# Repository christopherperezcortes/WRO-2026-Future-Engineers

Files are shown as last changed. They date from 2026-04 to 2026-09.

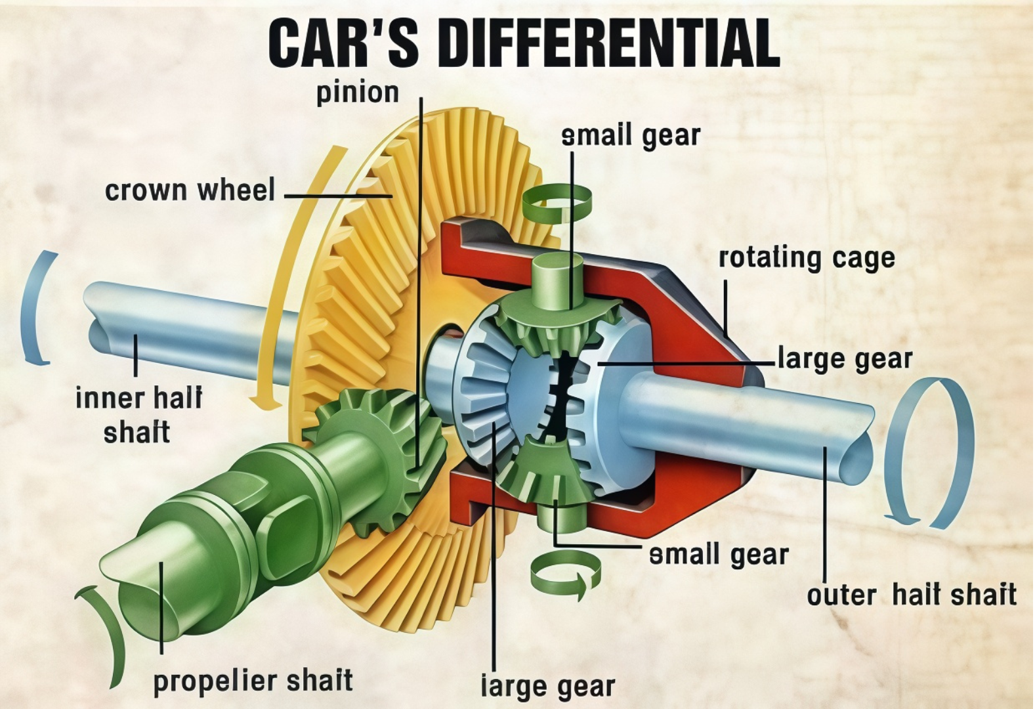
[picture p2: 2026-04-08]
OTHERS/CAR´S DIFFERENTIAL.png

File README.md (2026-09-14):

# Superiores — WRO 2026 Future Engineers

Team Superiores banner

This repository contains the engineering documentation, source code, mechanical designs, electrical system and test evidence for Team Superiores' autonomous vehicle for WRO 2026 Future Engineers.

## Team and competition

- **Team:** Superiores / Los Grises Superiores
- **Category:** WRO 2026 Future Engineers
- **Vehicle type:** Four-wheel autonomous vehicle with rear traction and front Ackermann-style steering
- **Students:** Christopher Pérez Cortés and Bárbara Daiana García Balboa
- **Coach:** Eduardo Alvarado González
- **Country:** Mexico
- **Competition event:** [PENDING: official event name and date]

WRO 2026 requires the Open Challenge vehicle to complete three laps. In the Obstacle Challenge it must complete three laps, obey red and green traffic signs, return to the starting section and perform parallel parking.

## Project status

The final physical robot uses a distributed three-controller architecture:

- A DFRobot FireBeetle ESP32 is the main controller.
- An Arduino Nano reads five HC-SR04 ultrasonic sensors and controls the lighting.
- An OpenMV camera performs color and shape detection.
- A BNO085 supplies fused heading data.
- A TB6612FNG drives the rear traction motor.
- A micro-servo actuates the steering rack.

The current software evidence contains two obstacle variants:

1. A three-lap build that stops without parking.
2. A four-lap experimental build containing parking logic.

Neither should be declared as the final WRO competition build until the parking logic starts immediately after the third lap and is validated on the official parking geometry.

The Open Challenge build must also have Wi-Fi disabled and use the WRO-required start-button procedure before it is tagged as a competition release.

## Design objectives

Our design objectives are:

1. Remain inside the WRO limit of 300 × 200 × 300 mm.
2. Remain below 1.5 kg.
3. Use a mechanically linked driving axle instead of differential steering.
4. Maintain controllable steering in both 600 mm and 1000 mm corridors.
5. Detect red and green pillars early enough to pass on the required side.
6. Count laps in clockwise and counter-clockwise rounds.
7. Stop safely when critical sensing or communication is lost.
8. Complete repeatable parallel parking after exactly three obstacle laps.
9. Make the vehicle reproducible from public source code, CAD, wiring and test records.

Current measured dimensions: **[PENDING: length × width × height]**

Competition-ready weight: **[PENDING: measured weight with batteries]**

## System architecture

```mermaid
flowchart LR
    BAT["2 × 18650 battery pack<br/>7.4 V nominal"]
    SW["Power switch"]
    REG5["5 V regulation"]
    REG33["3.3 V regulation"]
    SERREG["Servo 5 V rail"]
    LEDREG["LED 5 V rail"]
    ESP["FireBeetle ESP32<br/>main controller"]
    NANO["Arduino Nano<br/>sensor hub"]
    CAM["OpenMV<br/>vision processor"]
    IMU["BNO085<br/>fused heading"]
    US["5 × HC-SR04"]
    ENC["Motor encoder"]
    TB["TB6612FNG"]
    MOTOR["Rear traction motor"]
    SERVO["Steering servo"]
    LED["NeoPixel lighting"]

    BAT --> SW
    BAT --> REG5
    BAT --> REG33
    BAT --> SERREG
    BAT --> LEDREG
    SW --> TB
    REG5 --> ESP
    REG5 --> NANO
    REG5 --> US
    REG33 --> CAM
    REG33 --> IMU
    SERREG --> SERVO
    LEDREG --> LED

    US --> NANO
    NANO <-->|"I2C 0x08"| ESP
    IMU -->|"I2C 0x4B/0x4A"| ESP
    CAM -->|"UART 19200, CSV"| ESP
    ESP -->|"P,0 / P,1 and telemetry"| CAM
    ENC --> ESP
    ESP --> TB
    TB --> MOTOR
    ESP --> SERVO
    ESP -->|"brightness command"| NANO
    NANO --> LED
```

The electrical diagram reflects the current PCB evidence. Exact regulator loading, battery capacity, protection devices and installed LED topology remain to be measured or confirmed.

## Mechanical design

### Chassis

The 2026 chassis replaced an earlier LEGO-based prototype with printed structural parts. The reason reported in the Engineering Journal was that the LEGO structure occupied too much space and made electronics and sensor placement difficult.

The printed structure includes:

- Lower and upper chassis bodies.
- Front steering structure.
- Central and lateral ultrasonic mounts.
- Rear supports.
- Camera and electronics mounting areas.
- Mounting points for LEGO Technic drivetrain and steering elements.

Development evidence records two important mechanical iterations:

- Parts were sanded when printed clearances did not fit the motor and servo.
- The final chassis needed additional clearance around the drivetrain after a reprint created excessive friction.

The repository currently contains renders only. Native CAD, STL, STEP, drawings, print settings and revision identifiers are required in [`models/`](models/).

### Ackermann-style steering

The front axle uses a micro-servo and a rack-and-pinion linkage. The linkage causes the front wheels to steer together without using differential drive.

Current software settings are:

- Servo center: 90°.
- Maximum software correction: ±40°.
- PWM frequency: 50 Hz.
- Pulse range: 500–2500 µs.
- Parking correction magnitude: 38° in the experimental build.

The exact installed servo is **[PENDING: SG90 or Steren MOT-110, confirmed by a label photograph]**.

To make the Ackermann claim reproducible, the project still needs:

- Wheelbase.
- Front and rear track widths.
- Inner and outer wheel angles.
- Rack travel.
- Minimum turning radius.
- Drawing of steering pivots and tie-rod geometry.

### Traction

The robot uses one rear traction motor connected mechanically to the rear wheels through gearing/differential components. The motor is controlled by channel A of a TB6612FNG.

Current source settings:

- Open Challenge normal command: 100%.
- Open Challenge corner/near-wall minimum: 70%.
- Obstacle Challenge normal command: 70%.
- Obstacle visual-alert command: 40%.
- Obstacle reverse recovery: 45%.
- Parking approach/manoeuvre: 20%/18%.

These percentages are controller commands, not measured linear speeds. Motor model, no-load RPM, stall torque, gearbox ratio and measured vehicle speed are still required.

## Electronics

### Power architecture

The schematic shows a nominal 7.4 V two-cell 18650 supply, a motor-power switch, two Mini-560 regulator modules, two 7805 regulators, a voltmeter and separate named rails for logic, OpenMV/BNO085, servo and LEDs.

The current schematic does not show a fuse or reverse-polarity protection. Earlier development documentation records a reversed-battery incident that damaged a PCB. Protection must be added only after it is actually designed, installed and tested; it must not be claimed in documentation beforehand.

Measured power budget: **[PENDING: publish rail voltage, average current, peak current and regulator temperature]**

### Controllers

| Controller | Real responsibility |
|---|---|
| FireBeetle ESP32 | Main mission logic, steering, motor, BNO085, encoder, lap count, sensor fusion and communications |
| Arduino Nano | Sequential acquisition of five HC-SR04 sensors, I2C slave packet and NeoPixel output |
| OpenMV | QVGA color/shape processing for pillars, collision area, black-wall ROI and magenta parking boundaries |

### Sensors

#### Five HC-SR04 sensors

| Sensor | Position | Nano pins | Main use |
|---|---|---|---|
| S1 | Left, 90° | TRIG D2 / ECHO D3 | Outer-left distance and parking boundary |
| S2 | Left, 25° | TRIG D4 / ECHO D5 | Left corridor alignment |
| S3 | Front | TRIG D6 / ECHO D7 | Corner proximity, emergency reverse and parking stop |
| S4 | Right, 25° | TRIG D8 / ECHO D9 | Right corridor alignment |
| S5 | Right, 90° | TRIG D10 / ECHO D11 | Outer-right distance and parking boundary |

The Nano scans in the order S3, S1, S5, S2, S4. Each echo has a 12 ms timeout and a 2,000 mm maximum accepted distance. Invalid values are transmitted as `0xFFFF`.

#### BNO085

The BNO085 shares the I2C bus with the Nano and is tried at addresses `0x4B` and `0x4A`. The ESP32 requests `SH2_GAME_ROTATION_VECTOR` reports every 10 ms and derives yaw from the quaternion.

The BNO085 is used for:

- Locking the clockwise/counter-clockwise turn sign.
- Accumulating heading changes.
- Confirming each 90° corner.
- Counting three laps.
- Guiding reverse recovery.
- Controlling parking arc/contra-arc heading in the experimental build.

#### OpenMV

The camera captures QVGA RGB565 images at 320 × 240. It initially enables automatic gain, white balance and exposure, waits 800 ms, then freezes the selected values. The exact exposure remains automatic at boot and must be recorded during final calibration.

UART settings:

- OpenMV UART bus 3.
- ESP32 UART2.
- 19200 baud, 8N1.
- OpenMV TX → ESP32 RX/GPIO25.
- OpenMV RX ← ESP32 TX/GPIO26.
- Shared ground.

## Software architecture

Complete software details are in [`src/README.md`](src/README.md).

### Main data flow

```mermaid
flowchart LR
    U["Five ultrasonic readings"] --> F["Validity checks and last-echo retention"]
    C["OpenMV blobs and parking fields"] --> P["Frame validation and target selection"]
    B["BNO085 quaternion"] --> Y["Yaw and corner accumulation"]
    E["Encoder pulses"] --> S["Start/movement and parking progress"]
    F --> D["Mission decision"]
    P --> D
    Y --> D
    S --> D
    D --> ST["Steering command"]
    D --> MT["Motor command"]
    D --> FB["Failsafe / recovery / stop"]
```

### Open Challenge

The Open program uses the left/right ultrasonic error:

```text
error = (S1 + S2) - (S4 + S5)
```

It applies PID control with:

- `KP = 0.04`
- `KI = 0.001`
- `KD = 0.003`
- Integral contribution limited to ±8°.
- Derivative filter coefficient `0.25`.
- Steering changes limited to 10° per sensor update.

The front sensor gradually increases control strength and reduces speed between 1,000 mm and 300 mm. A frontal reading at or below 300 mm starts a brake/reverse recovery; forward travel resumes at or above 450 mm.

A BNO085-based guard is applied around each 90° corner. The mission ends after twelve confirmed quarter turns.

### Obstacle Challenge

OpenMV assigns:

- ID 5 to red.
- ID 3 to green.
- ID 0 to no pillar.

The OpenMV sends the lower-left reference of green pillars and the lower-right reference of red pillars. The ESP32 targets:

- Red at normalized X = −45, keeping it to the left so the robot passes on its right.
- Green at normalized X = +45, keeping it to the right so the robot passes on its left.

Camera control is proportional with `KP_CAMARA=1.0` and a ±30° limit. When no valid pillar exists, proportional corridor control uses `KP_PASILLO=4.0`.

If OpenMV communication is lost for 500 ms, the program clears the pillar target and falls back to ultrasonic corridor control. If Nano distance packets are lost for 250 ms or S3 remains invalid, movement stops.

### Obstacle state machine

```mermaid
stateDiagram-v2
    [*] --> ESPERANDO
    ESPERANDO --> RODANDO: encoder movement detected

    RODANDO --> FRENANDO_ESCAPE_FRONTAL: S3 <= 350 mm for 2 samples
    BUSCANDO_ESTACIONAMIENTO --> FRENANDO_ESCAPE_FRONTAL: S3 emergency
    FRENANDO_ESCAPE_FRONTAL --> RETROCEDIENDO_ESCAPE_FRONTAL: 150 ms
    RETROCEDIENDO_ESCAPE_FRONTAL --> FRENO_TRAS_ESCAPE: S3 >= 500 mm
    RETROCEDIENDO_ESCAPE_FRONTAL --> ESPERANDO_DESPEJE_ESCAPE: 2500 ms timeout
    ESPERANDO_DESPEJE_ESCAPE --> FRENO_TRAS_ESCAPE: S3 >= 500 mm
    FRENO_TRAS_ESCAPE --> RODANDO: previous phase was RODANDO
    FRENO_TRAS_ESCAPE --> BUSCANDO_ESTACIONAMIENTO: previous phase was parking search

    RODANDO --> BUSCANDO_ESTACIONAMIENTO: current experimental build reaches 3 laps
    BUSCANDO_ESTACIONAMIENTO --> LOCALIZANDO_PRIMER_DELIMITADOR: 3 magenta confirmations
    LOCALIZANDO_PRIMER_DELIMITADOR --> ESPERANDO_ENTRADA_HUECO: lateral boundary <= 260 mm
    ESPERANDO_ENTRADA_HUECO --> AVANCE_LIBRE_ENTRADA: gap >= max(320 mm, boundary + 80 mm)
    AVANCE_LIBRE_ENTRADA --> ARCO_ENTRADA_FRONTAL: >= 550 ms and >= 4 encoder pulses
    ARCO_ENTRADA_FRONTAL --> CONTRAARCO_ENTRADA_FRONTAL: heading change >= 55 degrees
    CONTRAARCO_ENTRADA_FRONTAL --> CENTRANDO_EN_CAJON: within 3 degrees of original heading
    CENTRANDO_EN_CAJON --> FRENO_FINAL_ESTACIONAMIENTO: S3 <= 70 mm after minimum travel
    FRENO_FINAL_ESTACIONAMIENTO --> TERMINADO: 180 ms
```

**Compliance warning:** the experimental program counts a fourth lap during the parking search. The competition build must enter parking after the third lap without completing a fourth lap.

## Parking strategy

The experimental strategy combines:

1. OpenMV detection of wide magenta blobs.
2. Three-frame wall confirmation.
3. Two-frame gap confirmation.
4. Selection of the parking side from the camera X position or the outside of the established round direction.
5. S1 or S5 to detect the first magenta boundary and the opening.
6. A forward arc of 38° steering until a 55° heading change.
7. A counter-arc until the original heading is recovered within 3°.
8. Straight movement until S3 reaches 70 mm.
9. Active braking and final stop.

This is implemented but is not yet supported by a complete WRO-format video or test dataset. See [`docs/parking-strategy.md`](docs/parking-strategy.md).

## Vision strategy

Important active OpenMV parameters include:

- Red thresholds:
  - `(22,48,38,63,16,46)`
  - `(28,52,43,65,17,49)`
- Green threshold:
  - `(35,75,-50,-15,-20,25)`
- Magenta threshold:
  - `(35,90,30,70,-50,5)`
- Red/magenta classifier:
  - Parking accepted at B mean ≤ 0.
  - Red pillar accepted at B mean ≥ 12.
- Pillar minimum area: 60 px box area.
- Minimum pillar density: 60%.
- Parking minimum width/height/area: 20 px / 6 px / 120 px.
- Parking minimum width-to-height ratio: 1.40.
- Parking minimum density: 55%.

These values are current code settings, not universal values. They must be revalidated using the real competition lighting and physical objects.

## Calibration and testing

- [`docs/calibration.md`](docs/calibration.md) contains reproducible procedures and source constants.
- [`docs/testing/protocol.md`](docs/testing/protocol.md) defines controlled tests.
- [`docs/testing/results.csv`](docs/testing/results.csv) stores every attempt.
- [`docs/compliance-checklist.md`](docs/compliance-checklist.md) records rule compliance.

Existing README success rates have not been retained as verified results because their source records were not found.

## Engineering iterations

Evidence currently supports the following development path:

1. LEGO/EV3 prototype.
2. Transition to a printed chassis.
3. Sensor expansion from three to five ultrasonic sensors.
4. HuskyLens experimentation followed by OpenMV.
5. Servo and steering-mechanism iterations.
6. Custom PCB and correction of solder bridges.
7. Replacement of a PCB after reverse-polarity damage.
8. BNO085 lap counting.
9. OpenMV firmware 5 to firmware 6, including red/magenta classification.
10. Addition of frontal recovery and experimental parking states.

See [`docs/engineering-journal/engineering-journal.md`](docs/engineering-journal/engineering-journal.md).

## Photographs

| Front | Back |
|:---:|:---:|
| Front | Back |

| Left | Right |
|:---:|:---:|
| Left | Right |

| Top | Bottom |
|:---:|:---:|
| Top | Bottom |

Team photograph:

Team Superiores

## CAD and fabrication

Mechanical files belong in [`models/`](models/). At present, only renders are available.

Required before final submission:

- [ ] Native CAD source or public view-only project.
- [ ] STL for every printed part.
- [ ] STEP for every custom part.
- [ ] Dimensioned drawings.
- [ ] Print settings and material.
- [ ] Revision that matches the photographed robot.

The PCB schematic, fabrication PDF, Gerbers and BOM belong in [`schemes/`](schemes/).

## Source code

| Target | Location |
|---|---|
| ESP32 Open Challenge | `src/esp32-main/open-challenge/` |
| ESP32 Obstacle Challenge | `src/esp32-main/obstacle-challenge/` |
| Arduino Nano sensor hub | `src/nano-sensor-hub/` |
| OpenMV firmware | `src/openmv/` |
| Calibration/test utilities | `src/esp32-main/tools/` |

## Build and upload

1. Inspect the battery polarity and keep the motor-power rail disconnected.
2. Upload the Nano sensor-hub sketch.
3. Upload `color_corner_v6.py` to the OpenMV and configure it as the boot script.
4. Upload the chosen ESP32 challenge build.
5. Verify I2C addresses `0x08` and `0x4B`/`0x4A`.
6. Verify UART at 19200 baud.
7. Center the steering with the wheels lifted.
8. Confirm motor direction with the wheels lifted.
9. Run the calibration checklist.
10. For competition, verify Wi-Fi/Bluetooth are disabled and use the single start button.

Exact IDE, core and library versions are listed in `src/README.md` once confirmed.

## Videos

| Open Challenge | Obstacle Challenge |
|:---:|:---:|
| Open Challenge (https://www.youtube.com/watch?v=diX7vBUeAKw) | Obstacle Challenge (https://www.youtube.com/watch?v=LjnSCSj2Bsk) |
| 1:14 autonomous driving demonstration | 1:43 obstacle-driving demonstration; parking is not shown |

Detailed video metadata and required replacement footage are documented in [`video/video.md`](video/video.md).

## Repository organization

```text
src/       source code for all programmed controllers
models/    native CAD, STEP, STL, drawings and renders
schemes/   electrical schematic, editable PCB, Gerbers and BOM
docs/      journal, build, calibration, strategy and testing
v-photos/  six required vehicle views
t-photos/  team photographs
video/     YouTube links and recording metadata
archive/   clearly labelled historical material
```

## License

Software and documentation licensing: see [`LICENSE`](LICENSE).

Hardware/CAD licensing: **[PENDING: confirm whether the MIT license is also intended to cover hardware design files]**

## Official references

- [WRO 2026 Future Engineers rules](https://wro-association.org/wp-content/uploads/WRO-2026-Future-Engineers-Self-Driving-Cars-General-Rules.pdf)
- [WRO 2026 documentation rubric](https://wro-association.org/wp-content/uploads/WRO-2026-Future-Engineers-Documentation-Rubric.pdf)
- [WRO Future Engineers repository template](https://github.com/World-Robot-Olympiad-Association/wro2022-fe-template)
- [WRO 2026 Questions & Answers](https://wro-association.org/competition/questions-answers/)

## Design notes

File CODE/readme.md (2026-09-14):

# Software Architecture and Upload Guide

## Declared controller roles

| File | Hardware | Function | Inputs | Outputs | Dependencies |
|---|---|---|---|---|---|
| `esp32-main/open-challenge/ESP32_Open_Optimized.ino` | FireBeetle ESP32 DFR0478 | Open Challenge PID, recovery, BNO085 lap count and final stop | Nano I2C, BNO085 I2C, encoder | Servo, TB6612, Nano brightness | `Wire`, `Adafruit_BNO08x`, `WiFi`, `WebServer` |
| `esp32-main/obstacle-challenge/experimental/ESP32_Obstacle_Parking_4_Laps.ino` | FireBeetle ESP32 | Obstacle navigation and experimental parking | OpenMV UART, Nano I2C, BNO085, encoder | Servo, TB6612, OpenMV mode, Nano brightness | `Arduino`, `Wire`, `Adafruit_BNO08x`, `Preferences` |
| `esp32-main/obstacle-challenge/competition-candidate/ESP32_Obstacle_3_Laps_No_Parking.ino` | FireBeetle ESP32 | Exactly three obstacle laps, then stop | OpenMV UART, Nano I2C, BNO085, encoder | Servo, TB6612, Nano/OpenMV commands | Same as above |
| `nano-sensor-hub/Nano_Sensors_I2C.ino` | Classic Arduino Nano | Five ultrasonic sensors and NeoPixels | HC-SR04 echoes, I2C brightness byte | 10-byte I2C distance packet, LED data | `Wire`, `Adafruit_NeoPixel` |
| `openmv/color_corner_v6.py` | OpenMV [PENDING exact model] | Red/green pillar, black ROI, magenta wall/gap detection | Camera image, ESP32 UART commands | 13-field CSV UART frame | OpenMV `sensor`, `time`, `micropython`, `machine.UART` |
| `esp32-main/tools/servo-center/ESP32_Center_Servo.ino` | FireBeetle ESP32 | Mechanical servo centering | — | Servo PWM | ESP32 Arduino core |
| `esp32-main/tools/openmv-uart-reader/ESP32_Read_OpenMV.ino` | FireBeetle ESP32 | Bench UART validation | OpenMV UART | USB serial | ESP32 Arduino core |

## Release status

| Build | Status |
|---|---|
| Open Challenge | Functionally advanced, but Wi-Fi is enabled and the WRO start button is not implemented |
| Three-lap obstacle build | Correct lap count, but parking disabled |
| Four-lap parking build | Parking implemented, but lap sequence conflicts with the three-lap rule |
| OpenMV v6 | Current vision candidate |
| Nano 3×8 | Current source candidate; installed LED topology must be confirmed |

A final release must contain exactly one competition program for each challenge and a configuration table recording every changed constant.

## Physical connections

### ESP32

| Function | ESP32 pin |
|---|---|
| Servo signal | GPIO27 / D4 |
| TB6612 PWMA | D6 |
| TB6612 AIN2 | D7 |
| TB6612 AIN1 | D8 |
| Encoder A | D5 |
| Encoder B, Open build | D9 |
| OpenMV RX | GPIO25 / D2 |
| OpenMV TX | GPIO26 / D3 |
| I2C SDA | GPIO21 |
| I2C SCL | GPIO22 |
| Start button | **[MISSING: assign and document a safe input pin]** |

### Nano

| Function | Pin |
|---|---|
| S1 left 90° TRIG/ECHO | D2/D3 |
| S2 left 25° TRIG/ECHO | D4/D5 |
| S3 front TRIG/ECHO | D6/D7 |
| S4 right 25° TRIG/ECHO | D8/D9 |
| S5 right 90° TRIG/ECHO | D10/D11 |
| NeoPixel data | D12 |
| I2C SDA/SCL | A4/A5 |
| I2C address | `0x08` |

## Inter-controller protocols

### Nano → ESP32 I2C

The Nano is a slave at `0x08`. The ESP32 requests ten bytes:

```text
S1_LOW,S1_HIGH,S2_LOW,S2_HIGH,S3_LOW,S3_HIGH,S4_LOW,S4_HIGH,S5_LOW,S5_HIGH
```

Each value is unsigned millimetres, little-endian. `0xFFFF` means invalid/no accepted echo.

### ESP32 → Nano I2C

One byte from 0 to 100 requests the LED brightness percentage.

### OpenMV → ESP32 UART

```text
ID,X,Y,AREA,ROI,COLLISION,BLACK_WALL,
PARKING,PARKING_X,PARKING_AREA,
GAP,GAP_X,GAP_WIDTH\n
```

| Field | Meaning |
|---|---|
| `ID` | 0 none, 3 green, 5 red |
| `X` | Reference X normalized from −100 to +100 |
| `Y` | Reference Y in 0–239 pixels |
| `AREA` | Blob box area |
| `ROI` | 0 none, 1 high, 2 low |
| `COLLISION` | 0, 3 or 5 |
| `BLACK_WALL` | Central black ROI flag |
| `PARKING` | Valid wide magenta boundary |
| `PARKING_X` | Boundary center X |
| `PARKING_AREA` | Boundary area |
| `GAP` | Valid gap between two boundaries |
| `GAP_X` | Gap center X |
| `GAP_WIDTH` | Gap width in pixels |

UART is 19200 baud, 8 data bits, no parity and one stop bit.

### ESP32 → OpenMV UART

```text
P,0\n  # disable parking detection
P,1\n  # enable parking detection
T,servo,motor,S1,S2,S3,S4,S5\n  # optional display telemetry
```

## Control flow and priorities

### Open Challenge

1. Initialize I2C, BNO085, servo, motor and LEDs.
2. Collect ten stationary corridor-width samples.
3. Apply a low motor command while waiting for encoder motion.
4. After movement is detected, ramp speed for five seconds.
5. Run wall-centering PID.
6. Reduce speed near front/lateral walls.
7. Apply the 90° heading guard.
8. Reverse if S3 is critically close.
9. Count twelve confirmed corners.
10. Perform the configured final-position adjustment.
11. Stop and latch mission completion.

The current movement-detection start is not a replacement for the WRO-required pushbutton.

### Obstacle Challenge priority

Highest to lowest:

1. Final stop or parking emergency.
2. Missing distance packet/S3 invalid.
3. Front brake/reverse recovery.
4. Parking state control.
5. Valid OpenMV pillar control.
6. Ultrasonic corridor control.
7. Motor/servo output.
8. Telemetry and maintenance.

## Fallbacks

| Failure | Current response |
|---|---|
| Nano packet missing >250 ms | Stop motor |
| S3 invalid after 125 ms retention | Stop motor |
| OpenMV UART missing >500 ms | Clear target and use corridor control |
| Invalid OpenMV line | Ignore and count/report invalid frame |
| Visual collision | Limit speed to 40%; S3 authorizes reverse |
| BNO085 missing | Retry at `0x4B` and `0x4A` |
| BNO085 data stops | Reinitialize after timeout |
| Reverse lasts 2.5 s without clearance | Stop and wait |
| Critical parking sensor invalid | Active braking/cancel parking |
| Parking phase timeout | Active braking/cancel parking |

The Open build currently allows motion without BNO085 because `EXIGIR_BNO085_PARA_MOVERSE=false`. This may prevent mission completion and must be deliberately resolved after testing.

## Required toolchain record

Fill this table from the exact competition laptop:

| Tool | Version |
|---|---|
| Arduino IDE | `[PENDING]` |
| ESP32 board package | `[PENDING]` |
| Selected FireBeetle board definition | `[PENDING]` |
| Adafruit BNO08x | `[PENDING]` |
| Adafruit NeoPixel | `[PENDING]` |
| OpenMV IDE | `[PENDING]` |
| OpenMV firmware | `[PENDING]` |
| Python/MicroPython API version | `[PENDING]` |

## Upload procedure

### Arduino Nano

1. Disconnect motor power.
2. Connect the Nano by USB.
3. Select the exact Nano board and bootloader used by the physical board.
4. Install Adafruit NeoPixel.
5. Confirm the real LED count/topology.
6. Compile and upload `Nano_Sensors_I2C.ino`.
7. Verify `0x08` on an I2C scan.

### OpenMV

1. Connect OpenMV to OpenMV IDE.
2. Open `color_corner_v6.py`.
3. Confirm UART bus and pins for the exact camera.
4. Run the calibration scene.
5. Record the selected exposure and LAB statistics.
6. Save the script as the camera boot program.
7. Verify 13-field CSV frames at 19200 baud.

### ESP32

1. Install the exact board package and BNO08x library.
2. Select the FireBeetle board definition.
3. Choose one declared challenge build.
4. For competition:
   - Disable Wi-Fi.
   - Disable all Bluetooth/RF.
   - Implement the single start pushbutton.
   - Verify the correct three-lap sequence.
5. Compile and upload.
6. Test first with wheels lifted.
7. Verify servo direction, motor direction, encoder, I2C and UART.

## Competition release procedure

1. Pass the compliance checklist.
2. Record every calibration value.
3. Run the repeatability protocol.
4. Commit all source and data.
5. Create a release/tag such as `wro-2026-national-v1.0`.
6. Record the commit SHA in the score sheet, journal and video description.
7. Do not change constants without creating a new version.

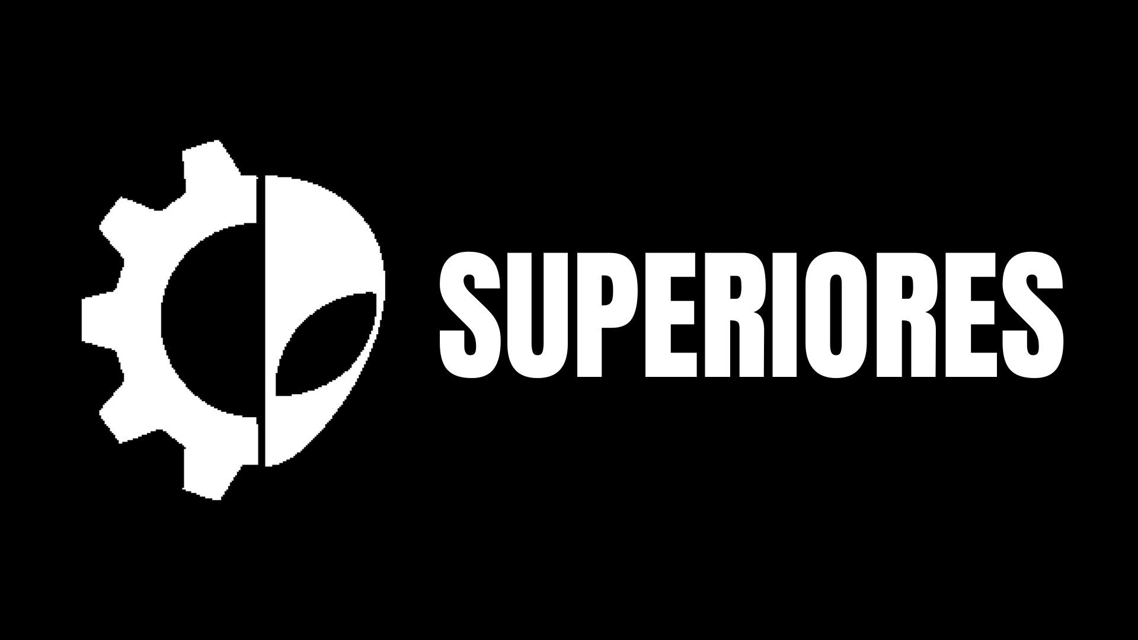
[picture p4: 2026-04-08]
LOS GRISES.png

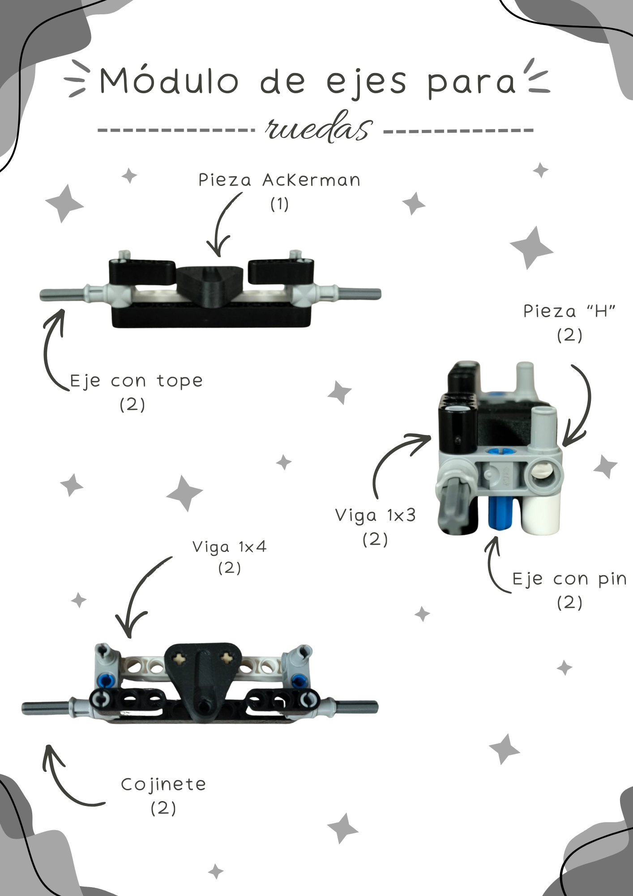
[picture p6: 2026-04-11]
OTHERS/LEGO wheel axle module.png

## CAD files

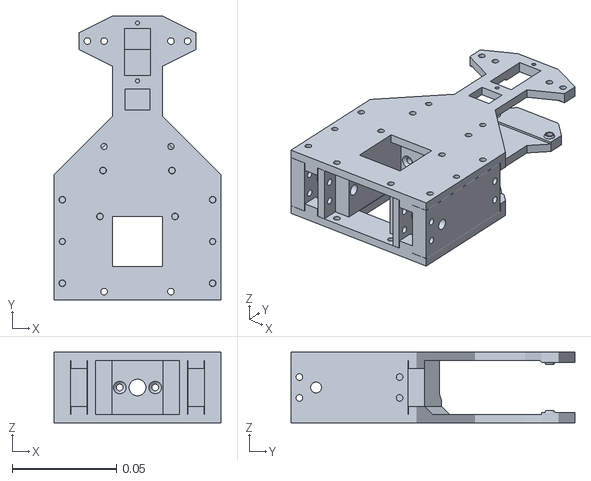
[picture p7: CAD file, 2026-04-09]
MODELS/CHASIS.stl
0.08 x 0.136 x 0.034

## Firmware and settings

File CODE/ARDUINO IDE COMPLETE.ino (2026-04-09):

#include <Wire.h>
#include "HUSKYLENS.h"
#include <Servo.h>

HUSKYLENS huskylens;
Servo direccion;

// MOTOR
#define IN1 5
#define IN2 6
#define ENA 3

// ULTRASONIC
#define TRIG_F 10
#define ECHO_F 11
#define TRIG_L 12
#define ECHO_L 13
#define TRIG_R A0
#define ECHO_R A1

// TURNS SENSOR
#define SENSOR_VUELTA 2
volatile int vueltas = 0;
unsigned long ultimaVuelta = 0;

// SERVO POSITIONS
#define CENTRO 90
#define IZQUIERDA 120
#define DERECHA 60

int velocidad = 140;

// Control
unsigned long tiempoColor = 0;
bool evitandoColor = false;

// INTERRUPTION
void contarVuelta() {
  if (millis() - ultimaVuelta > 800) {
    vueltas++;
    ultimaVuelta = millis();
  }
}

// DISTANCE
long medirDistancia(int trig, int echo) {
  digitalWrite(trig, LOW);
  delayMicroseconds(2);
  digitalWrite(trig, HIGH);
  delayMicroseconds(10);
  digitalWrite(trig, LOW);

  long duracion = pulseIn(echo, HIGH, 25000);

  if (duracion == 0) return 100;

  long distancia = duracion * 0.034 / 2;
  return distancia;
}

// ENGINE
void avanzar(int vel) {
  analogWrite(ENA, vel);
  digitalWrite(IN1, HIGH);
  digitalWrite(IN2, LOW);
}

void detener() {
  analogWrite(ENA, 0);
  digitalWrite(IN1, LOW);
  digitalWrite(IN2, LOW);
}

// SETUP
void setup() {
  Serial.begin(9600);

  pinMode(IN1, OUTPUT);
  pinMode(IN2, OUTPUT);
  pinMode(ENA, OUTPUT);

  pinMode(TRIG_F, OUTPUT);
  pinMode(ECHO_F, INPUT);
  pinMode(TRIG_L, OUTPUT);
  pinMode(ECHO_L, INPUT);
  pinMode(TRIG_R, OUTPUT);
  pinMode(ECHO_R, INPUT);

  pinMode(SENSOR_VUELTA, INPUT);

  attachInterrupt(digitalPinToInterrupt(SENSOR_VUELTA), contarVuelta, RISING);

  direccion.attach(9);
  direccion.write(CENTRO);

  Wire.begin();

  while (!huskylens.begin(Wire)) {
    Serial.println("Error HuskyLens");
    delay(100);
  }

  Serial.println("Sistema listo");
}

// LOOP
void loop() {

  if (vueltas >= 3) {
    detener();
    direccion.write(CENTRO);
    while (1);
  }

  long distF = medirDistancia(TRIG_F, ECHO_F);
  long distL = medirDistancia(TRIG_L, ECHO_L);
  long distR = medirDistancia(TRIG_R, ECHO_R);

  if (distF < 18) {
    velocidad = 110;
  } else if (distF < 30) {
    velocidad = 130;
  } else {
    velocidad = 150;
  }

  int diferencia = distL - distR;

  if (abs(diferencia) > 5) {
    if (diferencia > 0) {
      direccion.write(80);
    } else {
      direccion.write(100);
    }
    evitandoColor = false;
  }

  else if (distL < 10) {
    direccion.write(DERECHA);
    evitandoColor = false;
  }
  else if (distR < 10) {
    direccion.write(IZQUIERDA);
    evitandoColor = false;
  }

  else if (distF < 15) {

    if (distR > distL) {
      direccion.write(DERECHA);
    } else {
      direccion.write(IZQUIERDA);
    }

    evitandoColor = false;
  }
    
  // HUSKYLENS
  else {
    if (!evitandoColor && huskylens.request()) {
      if (huskylens.available()) {

        int bloques = huskylens.available();

        int mejorID = 0;
        int mejorArea = 0;
        int mejorX = 0;
        int mejorY = 0;

        for (int i = 0; i < bloques; i++) {
          HUSKYLENSResult r = huskylens.read();

          int area = r.width * r.height;

          // ===== SERIAL OF EVERYONE =====
          Serial.print("ID: ");
          Serial.print(r.ID);
          Serial.print(" | X: ");
          Serial.print(r.xCenter);
          Serial.print(" | Y: ");
          Serial.print(r.yCenter);
          Serial.print(" | Area: ");
          Serial.println(area);
          // ===========================

          if (area > mejorArea) {
            mejorArea = area;
            mejorID = r.ID;
            mejorX = r.xCenter;
            mejorY = r.yCenter;
          }
        }

        // ===== SERIAL DEL OBJETIVO =====
        Serial.print(">>> OBJETIVO: ID ");
        Serial.print(mejorID);
        Serial.print(" | X: ");
        Serial.print(mejorX);
        Serial.print(" | Y: ");
        Serial.println(mejorY);
        // =================================

        if (mejorID == 1) { // RED
          direccion.write(DERECHA);
          evitandoColor = true;
          tiempoColor = millis();
        }

        if (mejorID == 2) { // GREEN
          direccion.write(IZQUIERDA);
          evitandoColor = true;
          tiempoColor = millis();
        }
      }
    }

    if (evitandoColor) {
      if (millis() - tiempoColor > 300) {
        evitandoColor = false;
      }
    } else {
      direccion.write(CENTRO);
    }
  }

  avanzar(velocidad);
  delay(25);
}

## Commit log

2026-04-08 Rename Captura de pantalla 2026-04-08 122140.png to ARDUINO PCB .png
2026-04-08 Rename PCB 2026-04-08 122140.png to ARDUINO PCB 2026-04-08 122140.png
2026-04-08 Rename Captura de pantalla 2026-04-08 122300.png to ARDUINO PCB SCHEMATIC.png
2026-04-08 Create ARDUINO PCB 2026-04-08 122140.png
2026-04-08 Rename ARDUINO PCB 2026-04-08 122140.png to ARDUINO PCB.png
2026-04-08 Rename ARDUINO PCB SCHEMATIC.png to SCHEMES /ARDUINO PCB.png/ARDUINO PCB SCHEMATIC.png
2026-04-08 Rename SCHEMES /ARDUINO PCB.png/ARDUINO PCB SCHEMATIC.png to SCHEMES /main.py
2026-04-08 Rename SCHEMES /ARDUINO PCB.png/Captura de pantalla 2026-04-08 122140.png to SCHEMES/Captura de pantalla 2026-04-08 122140.png
2026-04-08 Rename SCHEMES /ARDUINO PCB.png/Captura de pantalla 2026-04-08 122300.png to SCHEMES /Captura de pantalla 2026-04-08 122300.png
2026-04-08 Rename Captura de pantalla 2026-04-08 122300.png to o.png
2026-04-08 Rename o.png to ARDUINO PCB SCHEMATIC.png
2026-04-08 Rename Captura de pantalla 2026-04-08 122140.png to ARDUINO PCB.png
2026-04-08 Rename 3178377.pdf to HUSKYLENS K210 AI VISION SENSOR.pdf
2026-04-09 Rename Part Studio 1.stl to CHASIS.stl
    [CHASIS.stl]
2026-04-09 Create ARDUINO IDE COMPLETE.ino
2026-04-10 Rename Angulo-Ackermann-dibujo.jpg to Ackerman steering.jpg
2026-04-11 Add IMU MPU6050 and TB6612FNG driver details to README
2026-04-11 Rename Módulo de ejes para ruedas LEGO.png to LEGO wheel axle module.png
2026-04-11 Revise voltage details and document HC-SR04 sensor
    Updated voltage specification for Arduino PCBs and added details about the HC-SR04 ultrasonic sensor, including its specifications and pin connections.
2026-04-21 Document PCB design and manufacturing details
    Added a section about the PCB design and manufacturing process.
2026-04-21 Update PCB section header formatting
    Changed PCB section header from bold to h3 format.
2026-04-21 Fix image tags in PCB section of README
    Updated image tags in the PCB section of the README.
2026-09-14 Add detailed readme for software architecture and guides
    Added a comprehensive readme detailing software architecture, controller roles, release status, physical connections, inter-controller protocols, control flow, fallbacks, toolchain records, upload pr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
